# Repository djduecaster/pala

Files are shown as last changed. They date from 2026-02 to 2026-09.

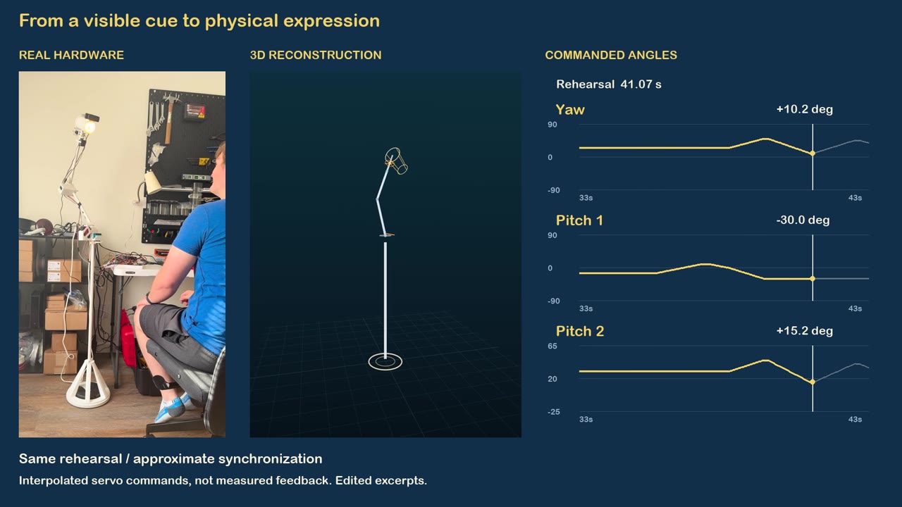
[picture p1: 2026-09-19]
docs/assets/pala-demo.jpg

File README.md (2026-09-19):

# PALA

**Programmable Autonomous Lamp Assistant** — a five-axis desk lamp with a little character.

PALA turns an IKEA NYMÅNE lamp into a physical desk companion. It notices someone sitting down, acknowledges a look toward its camera, celebrates a thumbs-up, follows a pointing direction, and settles back into a breathing rest pose. This is my first robotics portfolio project: custom printed mechanisms, embedded control, camera perception, and expressive motion brought together in a supervised V1 demo.

https://github.com/user-attachments/assets/bdd66a1e-fc92-461a-8403-59784bc540fe

**[Download the full-quality PALA V1 demo](https://github.com/djduecaster/pala/releases/tag/v0.1.0)** · 1 minute 47 seconds

The simulator and joint charts reconstruct commanded motion; they are not measured servo telemetry.

## The interaction

| You… | PALA… |
|---|---|
| Sit down and work | Makes a small noticing movement |
| Look toward the shade camera | Gives an expressive greeting |
| Give a thumbs-up | Leans forward, recoils, and adds coordinated yaw/pitch oscillations |
| Point left or right | Turns toward that general direction, then returns |
| Turn back to work | Disengages and settles into rest |
| Leave it resting | Breathes gently, with occasional yaw motion |

The performances were tuned on the real lamp through repeated operator ratings. Small movements often read poorly, so the final gestures use larger coordinated changes and distinct timing. The shade-mounted camera also shaped the resting posture: a useful view and a convincing pose had to work together.

## How it works

Gemini interprets a stationary camera snapshot and returns structured observations of presence, apparent attention, and visible gestures. Local Python logic decides whether an observation is fresh and appropriate for the current interaction stage, then selects a fixed performance. The model never supplies servo angles.

```mermaid
flowchart LR
    C[Shade camera] --> S[Stationary snapshot]
    S --> G[Gemini observation]
    G --> B[Local behavior gates]
    B --> P[Fixed performance]
    P --> T[Trajectory and limits]
    T --> H[PCA9685 / five servos]
```

The core runtime retains four independent loops: perception, behavior, control, and hardware. Their shared contracts are `PerceptionState → ActionPlan → HardwareCommand`. Latest-value exchange avoids queues of old camera frames; execution applies configured joint limits, and the hardware loop has a deadman timeout. The deadman is software-only, not an independent electrical emergency stop;
hardware operation requires supervision. See the [architecture guide](docs/architecture.md).

| Layer | Implementation |
|---|---|
| Mechanism | IKEA NYMÅNE lamp, custom 3D-printed servo mounts, five hobby-servo joints |
| Compute and actuation | NVIDIA Jetson, PCA9685 PWM driver |
| Vision | Logitech shade-mounted camera, GStreamer capture, Gemini image observations |
| Control | Python, deterministic choreography, calibrated joint-to-servo mapping |
| Development | Mac dummy backends, browser simulator, gesture workshop, optional telemetry |
| Capture | Optional FFmpeg POV recording and frame/command logs |

## Try it without hardware

Install Python 3.10–3.12 and [uv](https://docs.astral.sh/uv/), then:

```bash
git clone https://github.com/djduecaster/pala.git
cd pala
uv sync
PALA_MAX_RUNTIME_S=3 uv run python -m pala.main --mode dev
uv run pytest -q
```

The default runtime holds position using dummy backends. It does not start the live camera-driven performance or call Gemini.

For the local motion simulator:

```bash
uv run python tools/primitive_sim/run.py --scenario studio --port 8766
```

Open <http://127.0.0.1:8766/tools/primitive_sim/web/lamp_sim.html>. The [simulator guide](tools/primitive_sim/README.md) covers playback and joint checking. Simulation is a preview of commanded geometry, not a physical validation.

For the physical demo, follow the [Jetson workflow](docs/jetson_agent_workflow.md), then the [live interaction guide](docs/live_interaction.md). Hardware runs require the calibrated mechanism, a clear workspace, the established zero posture, and local credentials. The live tool moves to rest and automatically arms after its startup checks. Rest and shutdown zero are intentionally different positions.

## V1 boundaries

This is a working, supervised prototype rather than continuous human tracking. Model requests introduce variable latency; observations pause during motion, and the seated demo framing is deliberately constrained. Pointing selects left/right choreography rather than locating an exact object. Hobby servos provide no measured joint feedback, so commanded trajectories and simulator traces cannot establish actual position. The fifth joint is available but largely unused in the final gestures because of its mechanical limitations.

V1 is a completed portfolio milestone. A future version could improve the mechanism, sensing, and responsiveness, but those are separate work rather than requirements for this demo.

## Recreating and reusing PALA

Start with the [recreation guide](docs/recreating_pala.md) for parts, calibration,
system dependencies and staged bring-up. CAD/STL and a few hardware details are
still pending; this is a documented prototype rather than a complete build kit.
Software and textual documentation are [MIT licensed](LICENSE).
[Separate scope rules](docs/licensing.md) apply to media and CAD.

## Explore the project

- [Documentation index](docs/README.md): current guides and dated evidence
- [Live interaction](docs/live_interaction.md): behavior, controls, timing, and limitations
- [Gesture workshop](docs/gesture_workshop.md): pose and performance tuning
- [POV recording](docs/pov_recording.md): camera-only and live-demo capture
- [Robot configuration](config/robot.yaml) and [desk performances](config/desk_performances.json)
- [Portfolio media](docs/portfolio_media.md): release asset and local production archive

`pala/` contains the runtime; `tools/` contains operator tools and simulator sidecars; `tests/` covers contracts and software behavior. Videos, raw captures, model files, and archived working notes remain local and ignored by Git. Passing software tests does not establish physical acceptance of a new motion recipe.

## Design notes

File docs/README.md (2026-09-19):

# PALA documentation

PALA V1 is a supervised physical desk-companion demo. The default runtime holds
position; the opt-in live interaction uses camera snapshots and Gemini observations
to select locally controlled gestures. See the [project overview](../README.md).

| Guide | Purpose |
|---|---|
| [Recreating PALA](recreating_pala.md) | Parts, calibration, setup and remaining build details |
| [Licensing](licensing.md) | MIT software license and media/CAD scope |
| [Architecture](architecture.md) | Four loops, data contracts, model boundary, and safety limits |
| [Live interaction](live_interaction.md) | Current camera-driven V1 demo and rehearsal evidence |
| [Portfolio media](portfolio_media.md) | Demo release and ignored local production archive |
| [POV recording](pov_recording.md) | Optional live camera recording and stationary intro capture |
| [Manual interaction](manual_interaction.md) | Operator-triggered performances without Gemini |
| [Gesture workshop](gesture_workshop.md) | Tune and review individual physical performances |
| [Simulator](../tools/primitive_sim/README.md) | Local geometry, primitive tuning, and scripted playback |
| [Jetson workflow](jetson_agent_workflow.md) | SSH, tmux, deployment, and shared-shell conventions |
| [Telemetry](../tools/telemetry/README.md) | Optional camera/command viewer and historical replay |
| [Attention probe](attention_probe.md) | Stationary-view model diagnostic without model-triggered motion |
| [Single greeting test](live_greeting.md) | Earlier, explicitly armed one-greeting diagnostic |
| [Model transport](gemini_openai_sdk.md) | Generic endpoint diagnostics and credential conventions |
| [Memory boundary](memory_architecture.md) | Session bookkeeping and excluded persistent memory |
| [Workshop evidence](workshop_2026-09-07.md) | Dated operator ratings for specific gesture versions |
| [Known issues](bug_log.md) | Dated review backlog; entries are not newly reproduced findings |

Simulation and command traces do not measure physical joint position. Historical
ratings apply to the recorded recipe version, not automatically to later tuning.
Old competition, migration, and session-planning documents are outside the current
published guide set; source history preserves their context.

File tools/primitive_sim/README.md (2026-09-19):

# Lamp Sim (Sidecar Tool)

Lamp Sim is a sidecar workflow for quickly understanding primitives, joint geometry, and behavior loops before hardware runs.

It keeps runtime behavior math aligned by reusing `TrajectoryExecutor` from `pala/control/executor.py`.

## Unified shell (recommended)

Run the Lamp Sim sidecar server:

```bash
uv run python tools/primitive_sim/run.py --scenario studio --port 8766
```

Then open the unified shell:

```text
http://127.0.0.1:8766/tools/primitive_sim/web/lamp_sim.html
```

The shell provides navigation between Studio, Joint Checker, and Playback.
Generate a suite trace in Studio before opening Playback. All modes are local
simulation tools; they do not command hardware or establish physical acceptance.

## Primitive Studio mode (recommended)

Run the interactive tuning tool:

```bash
uv run python tools/primitive_sim/run.py --scenario studio --port 8766
```

Raw mode URL:

```text
http://127.0.0.1:8766/tools/primitive_sim/web/index.html?studio=1
```

Studio, Joint Checker, and Playback are available from this same server instance.

Studio features:
- Select any runtime primitive (`hold`, `home`, `move_to`, `gaze_to`, `glance`, `nod`, `breath`, `orient_to_zone`)
- Tune primitive command fields
- Live auto-run preview with configurable debounce (default 200ms)
- Run preview simulation with 3D lamp playback
- Compare mode: baseline (cyan) vs draft (orange) in `overlay` or `split`
- Save tuned values to baseline params
- Save all baseline params in one write (`Save All`)
- Reload from baselines on startup
- Camera toolbar (`zoom +/-`, `orbit <- ->`, `reset view`) + mouse-wheel zoom
- Parameter filter and expanded nudge controls (`--`, `-`, `+`, `++`)
- Top bar mode buttons: switch between Studio, Joint Checker, and Playback
- `Run Suite Trace` button: generates `logs/primitive_sim/latest_trace.json` and opens playback

## Joint checker mode

Run the dedicated joint slider page:

```bash
uv run python tools/primitive_sim/run.py --scenario joint_checker --port 8766
```

Raw mode URL:

```text
http://127.0.0.1:8766/tools/primitive_sim/web/joint_checker.html
```

Joint Checker, Studio, and Playback are available from this same server instance.

Joint checker features:
- Per-joint sliders generated from `joint_names` + `joint_limits_rad`
- Live angle readouts in radians and degrees
- 3D pose rendering driven by current slider values
- Camera toolbar (`zoom +/-`, `orbit <- ->`, `reset view`) + mouse-wheel zoom
- Per-joint `+/-` nudge buttons adjacent to angle input
- DH parameter table loaded from `config/robot.yaml`
- Top bar mode buttons and `Run Suite Trace` button

## Baseline params file

Default path:

```text
tools/primitive_sim/baseline_params.json
```

Override path:

```bash
uv run python tools/primitive_sim/run.py --scenario studio --baseline path/to/baseline.json
```

Baseline schema stores command defaults per primitive plus metadata:

```json
{
  "version": 2,
  "updated_by": "primitive_studio",
  "updated_at_utc": "2026-02-27T00:00:00Z",
  "primitives": {
    "breath": {"amp_rad": 0.08, "period_s": 6.5, "rate_rad_s": 1.0}
  }
}
```

Baseline loading is strict:
- Baseline files must already be v2.
- Missing primitive payloads or invalid command fields fail fast.

## Trace modes (existing CLI)

Generate suite trace:

```bash
uv run python tools/primitive_sim/run.py --scenario suite --serve
```

Generate one primitive trace:

```bash
uv run python tools/primitive_sim/run.py \
  --scenario single \
  --primitive nod \
  --duration-s 1.2 \
  --amp-rad 0.2 \
  --rate-rad-s 1.8 \
  --serve
```

Generate without serving:

```bash
uv run python tools/primitive_sim/run.py --scenario suite --output logs/primitive_sim/latest_trace.json
```

## Scripted scenarios

Use `--scenario script --script <file.json>`.

Script format:

```json
{
  "segments": [
    {
      "name": "home",
      "max_s": 2.0,
      "stop_on_done": true,
      "action": {
        "primitive": "home",
        "command": {"rate_rad_s": 1.2},
        "confidence": 1.0,
        "style": "calm"
      }
    }
  ]
}
```

## Viewer geometry sources

Viewer geometry is included in trace metadata and used by the 3D renderer.

Priority:
1. `dh_params`-derived values from `config/robot.yaml` (link lengths + theta offsets)
2. Explicit overrides from `lamp_geometry` sections
3. Viewer defaults for missing values

Pitch convention:
- Viewer defines all pitch joints about local `-Z`.
- Pitch1 and pitch3 use `theta = theta0 + q`.
- Pitch2 uses `theta = theta0 - q`: the operator confirmed positive pitch2
  opens/lifts the elbow away from the ground. This display convention applies
  to both Playback/Studio and Joint Checker; it does not reverse servo commands.

Supported override locations:
- `lamp_geometry`
- `sim_viewer.lamp_geometry`
- `primitive_sim.lamp_geometry`
- `tools.primitive_sim.lamp_geometry`

Example:

```yaml
sim_viewer:
  lamp_geometry:
    mast_height_m: 1.28
    hub_rise_m: 0.02
    upper_arm_len_m: 0.52
    fore_arm_len_m: 0.42
    wrist_stub_len_m: 0.08
    shade_neck_len_m: 0.08
    shade_len_m: 0.18
    shade_base_radius_m: 0.068
    shade_tip_radius_m: 0.046
    pitch1_zero_offset_rad: 1.57079632679
    pitch2_zero_offset_rad: 0.0
    pitch3_zero_offset_rad: 0.0
```

## Scripted desk interaction (simulation only)

Generate the current expression study, then serve this repository locally:

```bash
uv run python -m tools.primitive_sim.social_scene
uv run python -m http.server 8766 --bind 127.0.0.1
```

Open:

```text
http://127.0.0.1:8766/tools/primitive_sim/web/index.html?studio=0&trace=/logs/primitive_sim/desk_scene.json
```

Use **Play / pause** above the lamp or jump between labeled moments. The scene
order and captions come from `tools/primitive_sim/desk_scene.json`; motion comes
from the same `config/desk_performances.json` recipes as the live demo.
Regenerate the trace after recipe changes instead of relying on an old duration
or a hand-copied pose list.

Human actions are captions. This tool makes no Gemini requests, opens no camera,
and writes no hardware output. It runs the production executor at 80 Hz with
unity style scales and 1e-6-radian completion tolerance, and checks configured
target limits. It does not establish physical clearance, camera framing, measured
servo position, or recognition accuracy. For the real supervised behavior and its
rehearsal boundaries, see [live interaction](../../docs/live_interaction.md).

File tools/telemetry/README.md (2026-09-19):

# Telemetry sidecar

Telemetry runs separately from the four-loop runtime. Its default live view
(`runtime_core`) shows the camera preview, capture freshness/source health,
actions, and commanded joint angles. Joint values are commands, not measured
servo position or proof of hardware application/deadman health.

The supervised demo's semantic observations and execution reports live in its
own run logs; see [live interaction](../../docs/live_interaction.md). Old V3/V4
reasoning, case review, and dataset modules remain for historical replay. Current
runs do not emit the deleted planner's semantic streams.

## Live viewer

Start the intended runtime separately, following its operator guide. From the
repository root on the Mac, with your SSH alias configured:

```bash
uv run python -m tools.telemetry.mac_viewer \
  --mode live --focus runtime --jetson-host jetson-wifi
```

The GUI needs a Tk-compatible Python interpreter. If your environment requires
one, set `UV_PYTHON` to that interpreter's path. Do not launch another runtime
just to view an already-running demo.

Read-only diagnostic checks are available with:

```bash
uv run python -m tools.telemetry.doctor --help
```

Capture timestamps and viewer receive times are separate. Monotonic clocks from
different machines cannot be subtracted directly. A command sampled alongside a
preview frame does not demonstrate physical execution.

## Saved sessions and historical tools

Use a new local session directory for capture:

```bash
uv run python -m tools.telemetry.pipeline capture \
  --save-session logs/telemetry/session_001 --jetson-host jetson-wifi
uv run python -m tools.telemetry.pipeline compile logs/telemetry/session_001
uv run python -m tools.telemetry.mac_viewer \
  --mode replay --replay logs/telemetry/session_001 --focus runtime
```

The pipeline also offers `review`, `export`, and `report`. Inspect the relevant
subcommand's `--help` before using historical curation features. Indexed review
requires a compiled `session.db`; historical case/reasoning panels may be empty
for current sessions. Their labels are not current runtime model decisions.

Capture artifacts can include frames, event JSONL, indexes, a SQLite database,
and quality reports. Keep these local, including any camera images. Quality
reports describe captured data health, not physical safety or robot reliability.
Known issues from prior review are tracked in the [issue backlog](../../docs/bug_log.md).

Telemetry failure must not prevent core control/safety operation. Optional
[POV recording](../../docs/pov_recording.md) uses its own encoder and timing logs.

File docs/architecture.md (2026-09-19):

# PALA Architecture

## Runtime Loops

- Perception loop: approximately 15-30 Hz
- Behavior loop: approximately 2-5 Hz
- Control loop: approximately 50-100 Hz
- Hardware loop: approximately 50-200 Hz with deadman timeout

The stable runtime contract remains:

```text
PerceptionState -> ActionPlan -> HardwareCommand
```

## Runtime modes

The default behavior emits one persistent `hold` action and uses dummy backends
in dev mode. Opt-in manual performances and the supervised camera/Gemini demo
share the same four loops and typed control/hardware contracts.

The [live interaction](live_interaction.md) runner uses stationary camera snapshots
for semantic observations. Local code selects and sequences fixed performances;
the model never writes joint targets or hardware commands.

## Perception

The active perception path performs capture only:

```text
FrameSource -> PerceptionNode -> LatestFrameCache + PerceptionState
```

`PerceptionState` reports frame identity, freshness, timing, FPS, and source
health. It does not report people, objects, zones, gestures, or pointing.

Local DeepStream detection is not part of the active runtime. Semantic image
interpretation runs only in the opt-in model tools.

## Behavior

The behavior package includes a hold-only default policy, manual performance
request gate, model transport clients, and validation for social observations.
The live-demo supervisor uses one model request in flight and rejects stale,
invalid, or context-mismatched results before requesting a local performance.

## Control and Hardware

Control remains deterministic. `TrajectoryExecutor` converts typed
`ActionPlan` objects into rate-limited, joint-clamped `HardwareCommand` objects.
The hardware loop applies commands through dummy or PCA9685 servo backends and
enforces the deadman timeout independently of behavior/model availability.

The configured rates are 20 Hz perception, 3 Hz behavior, 80 Hz control, and
120 Hz hardware. The deadman is a software check in the hardware thread; it
is not an independent electrical watchdog.

The executor uses latest-intent arbitration: a different intent replaces the
active primitive, equivalent intents preserve it, and a completed action ID
does not restart. `cancel_current` remains in the stable contract but is not
interpreted by the executor. Gesture sequencing must account for this behavior.

The executor starts at a software zero estimate and exposes commanded
completion, not measured physical arrival. The current servo interface has no
position feedback. Following operator confirmation with the calibration tool,
pitch2's software limits are -25 to +65 joint degrees. These match its
unsaturated servo mapping; scale 2 and offset 50 remain unchanged. Physical
behavior was confirmed by the operator, not measured by software feedback.

Simulation supplies a private clock to the same executor. It does not patch
global time or change the runtime's real monotonic clock. Configuration rejects
nonfinite or invalid rates/limits/styles, and the servo backend validates the
entire command before beginning channel writes. I2C failures during a valid
batch are still possible; software validation is not bus-level atomicity.

Standalone gesture dry-runs use dummy hardware regardless of runtime mode.
The main runtime's four-loop deadman does not apply to these standalone tools.

## Logging

The default runtime writes:

- `perception.jsonl`: capture state and source health
- `actions.jsonl`: emitted hold actions
- optional preview image and metadata files for telemetry

Manual/live runs also write `interaction.jsonl` and recipe/configuration snapshots.
Live model observations, source images, and session settings are recorded under
`logs/attention_probe/<session>/`; see the live interaction guide.

Live telemetry defaults to the runtime view. Joint positions and enable state
are explicitly commanded values; applied hardware and deadman status are
unavailable without a structured status producer. Historical reasoning,
capture/replay, and curation remain optional sidecar tooling.

## Opt-in manual performances

`--manual` enables the [manual interaction](manual_interaction.md). The supervisor
polls terminal commands without adding a worker loop. The behavior loop gates
requests and publishes immutable performance recipes through a latest-value
channel. The control loop expands each recipe into the existing typed
`ActionPlan` steps and executes them through `TrajectoryExecutor`;
`PerceptionState`, `ActionPlan`, and `HardwareCommand` schemas are unchanged.
Control feedback reports commanded completion to the behavior gate.

This control-rate sequencer preserves short holds, rejects normal preemption,
and permits an explicit shutdown trajectory from the current command estimate.
It uses unit style multipliers and 1e-6-radian commanded completion tolerance,
matching the workshop. Default executor tolerance remains unchanged. Rest and
zero are distinct. Ctrl-C stops without recovery. Once manual commands have
started, a hardware deadman expiry stops the session without automatic resume.

Manual runs add recipe/configuration snapshots and `interaction.jsonl` execution
reports; their `actions.jsonl` records step transitions instead of hold-only
decisions. The separate live-demo composition has supervised rehearsal evidence described
in the live interaction guide. This does not establish unattended reliability.

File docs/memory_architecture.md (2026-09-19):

# Behavior memory boundary

The default hold policy has no scene interpretation or model memory. The opt-in
live interaction maintains session-local state: current stage, active performance,
presence already noticed, greeting/excitement limits, pointing release/cooldown,
observation generation, and automatic rearming.

Presence persists across automatic rearms so a seated person does not repeatedly
trigger notice. Two valid absent observations at rest spanning four seconds allow
a later arrival to be noticed again. This is bookkeeping, not person recognition.
The state is not persistent identity or autobiographical memory. A separate
summarizer, long-term learning, and transcript memory are outside V1.

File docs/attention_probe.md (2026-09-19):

# Gemini attention probe

This experiment starts the existing four-loop manual runtime, enters rest, and
holds there while you collect four labeled observations. Gemini interprets apparent
attention toward the lamp; its answers never request movement. Startup and normal
shutdown are the only motion permitted in probe mode. The camera is on the shade,
Capture uses 1280×720 MJPEG at a requested 30 FPS. Stationary comparisons showed
wider horizontal coverage than 640×480 and essentially the same coverage as
1920×1080. The preview is downscaled without cropping.

This first experiment uses only the stable rest viewpoint. Current rest is
`[yaw=0, pitch1=-40, pitch2=+25, roll=0, pitch3=0]` in joint degrees.

## Offline Mac check

From the repository root:

```bash
uv run python -m tools.attention_probe --mode dev --probe-mock
```

Dummy camera, dummy servos, and explicitly labeled mock responses; no API call or
key needed. The mock always returns uncertain/wait and does not analyze the image.
Wait for `PROBE READY`, then type a number and press Enter.

| Number | Your position at the end of the countdown |
|---|---|
| 1 | Outside the frame: empty scene. |
| 2 | Walk into view without looking at the camera. |
| 3 | Look directly toward the camera. |
| 4 | Look toward the wall beside the camera. |

Each number starts a **five-second countdown**. Capture uses the first available
fresh frame taken after the deadline; scheduling/camera delay is logged. A frame
must be at most 500 ms old. If none arrives within two additional seconds, the
trial ends without an API call. Stay in position until `SNAPSHOT saved` appears.
Then you can return to the keyboard while Gemini responds.

Repeat numbers freely, one trial at a time. New trial requests while counting down
or awaiting a response are rejected rather than queued. Each request contains only
the image and a fixed resting-state prompt; the scenario number and description
are saved locally and deliberately excluded from the model input.

## Key and model setup on Jetson

Use a Gemini API key, not a browser login. Either export `GEMINI_API_KEY` in the
shell launching the runner, or save the key alone in a file outside the repository,
for example `~/.config/pala/gemini_api_key`, and use `--gemini-key-file` below.
`PALA_GEMINI_API_KEY` and `GOOGLE_API_KEY` are also recognized. No key is accepted
on the command line as a literal value or written to probe logs.

To create the key file without putting the key in shell history (Jetson Bash):

```bash
install -d -m 700 ~/.config/pala
(umask 077; read -r -s -p 'Gemini API key: ' key; echo;
 printf '%s' "$key" > ~/.config/pala/gemini_api_key)
chmod 600 ~/.config/pala/gemini_api_key
```

For a temporary environment variable instead (Jetson Bash):

```bash
read -r -s -p 'Gemini API key: ' GEMINI_API_KEY; echo
export GEMINI_API_KEY
export PALA_GEMINI_MODEL='YOUR_AVAILABLE_GEMINI_MODEL_ID'
```

If you maintain exports in `~/.config/pala/env.sh`, source it yourself in that
terminal first. The probe does not read or execute shell configuration files.
There is deliberately no hardcoded model version: use an image-capable Gemini
model available to your account. `--gemini-model` overrides `PALA_GEMINI_MODEL`.
Missing credentials/model fail before hardware initialization. The key's validity
and model access are checked only when the first trial makes a real request.

## Physical session

Stop the existing manual/workshop runtime first; do not start competing servo or
camera owners. After returning to and establishing zero, run in the shared `pala`
tmux session from `~/pala`:

```bash
uv run python -m tools.attention_probe --mode jetson_full --enable
```

Or with a key file:

```bash
uv run python -m tools.attention_probe --mode jetson_full --enable \
  --gemini-key-file ~/.config/pala/gemini_api_key \
  --gemini-model YOUR_AVAILABLE_GEMINI_MODEL_ID
```

Confirm `ZERO` when prompted. Startup moves to rest automatically. The ground-facing
zero view is not submitted. Wait for `PROBE READY` and use 1–4. Only the triggered
snapshots are sent to Google's Gemini API; there is no continuous upload. These
images and the responses are also saved locally.

- `help` / `?`: show the four scenarios and common commands.
- `status`: show runtime posture and progress.
- `cancel`: cancel a countdown; an already-sent API request cannot be recalled.
- `shutdown` / `q` / `quit`: return to zero, hold two seconds, disable, and exit.
- `stop` / `abort` / Ctrl-C: disable and exit without recovery motion.
- Closing input or first SIGTERM requests normal shutdown, as in the manual runner.

Gesture commands (`greet`, `demo`, etc.) are blocked in probe mode. The auxiliary
network worker cannot access the gesture gate or actuators. It uses a 20-second
request timeout and disables SDK retries; control and hardware loops continue
while waiting. Shutdown does not wait for that worker. An unfinished request is
logged as abandoned on exit; the remote service may still finish processing it.

## Results

Each trial prints person presence, apparent attention, `acknowledge` or `wait`, a
short visible-evidence sentence, and elapsed request/validation latency. These
are proposals only. An invalid or failed response is labeled explicitly, not
silently converted into a valid wait decision. A single snapshot cannot establish
walking direction or reliably measure precise eye gaze; sideways-looking case 4
is intentionally a useful ambiguity test.

Outputs live in a unique `logs/attention_probe/<timestamp>_<id>/` directory:

- `session.json`: model, timing, scenarios, mock flag, and posture context.
- `prompt.txt`: exact fixed prompt.
- `performances.json`: recipe snapshot, including exact rest angles for this run.
- `<trial-id>.jpg`: exact JPEG submitted (up to 960 pixels on its longest side).
- `trials.jsonl`: scenario labels, capture age/delay, provider response content and
  usage when available, validated decision, failures, and measured latency.

Normal runtime logs still live under `logs/runs/`. Logs/images are ignored by git.
Use `--probe-output PATH` to select another parent directory. Keep images private
unless you deliberately select them for a portfolio artifact.

The implementation reuses PALA's retained model transport and Google's documented
[OpenAI-compatible image input and JSON output interface](https://ai.google.dev/gemini-api/docs/openai).
It does not restore the removed behavior system. This first experiment tests
acknowledge-versus-wait from rest; sustained attention and disengagement are later
contracts, after we inspect the camera's attention posture.

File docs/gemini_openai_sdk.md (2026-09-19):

# Model transport diagnostics

The default runtime remains hold-only. Generic transport probes run independently
and do not actuate the lamp. The implemented camera/Gemini demo is documented in
[live interaction](live_interaction.md); its validated semantic observations
feed local gesture selection.

The surviving transport is under `pala/behavior/model_clients/`. It supports
provider-aware URL normalization and chat requests. `tools/model_provider_probe.py`
checks basic text and JSON responses; it no longer uses deleted V4 prompts,
skills, or decision schemas.

```bash
uv run python tools/model_provider_probe.py --help
```

For an explicitly configured model endpoint, use `--provider`, `--base-url`,
and `--model`, or the existing `PALA_MODEL_PROVIDER`, `PALA_COSMOS_BASE_URL`,
and `PALA_COSMOS_MODEL` variables. The probe reads credentials from
`PALA_COSMOS_API_KEY`; keep them in the local/Jetson secret environment, never
in shell examples committed to Git. Running the probe sends requests to the
configured service. A transport result does not establish behavior quality.

Image capture and image/video diagnostics remain in
`tools/capture_cosmos_api_inputs.py`, `tools/cosmos_image_probe.py`, and
`tools/cosmos_video_probe.py`. Their historical names remain for now. Inspect
each tool's help before use; camera source and endpoint must be explicit.

The `cosmos` configuration block is retained for these diagnostic tools.
`pala.main` does not consume its enabled flag to construct a planner. The old
runtime planner smoke script was removed because its assertions referenced
behavior that no longer exists.

Before changing a provider or model, check the selected provider's current model
and parameter documentation. Historical model IDs and quota assumptions are
not a current recommendation. See [Google's compatibility reference](https://ai.google.dev/gemini-api/docs/openai).

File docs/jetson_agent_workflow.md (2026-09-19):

# Jetson agent workflow

This document describes the direct Mac-to-Jetson workflow for agents and
operators. It is intentionally separate from the PALA runtime architecture:
the Jetson shell and tmux session are operator tooling, not another runtime
loop.

## First-time setup

Complete the [recreation guide](recreating_pala.md#software-environment) before
using the deployment scripts on a fresh Jetson. Their plain-venv bootstrap is not
a system dependency installer and does not expose system PyGObject/GStreamer.

## SSH paths

The development setup uses two locally configured SSH aliases (configure these
for your own Jetson before using the examples):

- `jetson`: the USB device-mode path at the `192.168.55.x` link-local address.
- `jetson-wifi`: the Jetson's normal Wi-Fi address.

Use `jetson-wifi` for direct agent work when Wi-Fi is available. The existing
deployment scripts currently call the `jetson` alias directly, so changing
`JETSON_HOST` on the `make` command line does not yet change where
`deploy_jetson.sh` or `run_jetson.sh` connect.

Check the resolved target before troubleshooting a connection:

```bash
ssh -G jetson-wifi | grep -E '^(hostname|user|port) '
```

## Shared tmux session

The `pala` tmux session lives on the Jetson. It stays alive independently of
the SSH connection, which lets an operator attach to the same shell that an
agent is using.

Create it if needed:

```bash
ssh -T jetson-wifi 'tmux new-session -A -d -s pala'
```

Attach from a visible Mac terminal:

```bash
ssh -t jetson-wifi 'tmux attach -t pala'
```

Detach with `Ctrl+B`, then `D`. Detaching leaves commands running. Typing
`exit` ends the shell in that tmux pane.

## Agent interaction

Agents should use one command at a time and capture the pane after the command
has had time to finish. The shared pane is an interactive surface, so an agent
should not send keys while the operator is typing or while an interactive
program owns the prompt.

Send a short, literal command visibly into the shared shell:

```bash
ssh -T jetson-wifi \
  'tmux send-keys -t pala -l "hostname; pwd"; tmux send-keys -t pala Enter'
```

Read the visible command and recent output:

```bash
ssh -T jetson-wifi 'tmux capture-pane -p -t pala -S -80'
```

Check the pane without changing it:

```bash
ssh -T jetson-wifi \
  'tmux display-message -p -t pala "#{pane_current_command} #{pane_current_path}"'
```

For commands that need reliable exit status, structured output, or complex
quoting, agents should use a normal noninteractive SSH command and report the
result in the conversation. `send-keys` is for shared visibility; it is not a
replacement for a script runner.

## Long-running PALA runs

Keep the shared `pala` shell available for inspection and run long-lived PALA
processes in a named tmux window:

```bash
ssh -T jetson-wifi \
  'tmux new-window -d -t pala: -n pala-run "cd ~/pala && ./run_on_jetson.sh"'
```

List windows and capture the run window:

```bash
ssh -T jetson-wifi 'tmux list-windows -t pala'
ssh -T jetson-wifi 'tmux capture-pane -p -t pala:pala-run -S -120'
```

Before starting another run, check whether `pala-run` already exists and
whether a runtime is still active. Do not stack multiple hardware runtimes on
the same Jetson.

## `make go` and a future tmux target

Today, `make go` does this:

1. `deploy_jetson.sh` synchronizes the Mac checkout to `~/pala`.
2. `run_jetson.sh` opens a foreground SSH command and runs
   `run_on_jetson.sh` directly.

That foreground behavior is useful for a normal agent command, but it does not
create or attach to tmux. Automatically attaching would also keep `make go`
running for the entire lifetime of PALA, which makes the command awkward for
noninteractive agents.

The preferred future change is an explicit opt-in target such as
`make go-tmux`:

- deploy to the selected SSH alias;
- start `run_on_jetson.sh` in a dedicated `pala` tmux window;
- return the command promptly;
- let the operator stay attached to the session and let the agent use
  `capture-pane` for text logs.

An optional `make go-attach` could provide the foreground attached behavior for
manual demonstrations. Keeping these behaviors separate avoids changing the
meaning of the existing `make go` command. Implementing either target requires
an explicit change to the deployment scripts and Makefile; this document does
not change those scripts.

## Safety and logging notes

- Keep Mac and Jetson paths explicit in every command.
- Use `PALA_LOG_LEVEL=INFO` or `DEBUG` only when the extra output is useful.
- Prefer the run-scoped files under `~/pala/logs/runs/` for post-run evidence;
  use `make pull-logs` after a run when its SSH target is correct.
- tmux persistence does not replace the runtime deadman timeout or any local
  hardware safety limit.

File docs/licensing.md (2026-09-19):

# License and scope

PALA's original software source and associated textual documentation are licensed
under the [MIT License](../LICENSE), copyright 2026 Dylan Duecaster. This includes
Python tools, browser simulator code and project configuration. Preserve the
copyright and license notice when redistributing covered material.

The MIT grant does **not** cover portfolio videos, photographs (including the
README thumbnail), audio/music, or CAD/mechanical design files. These materials
are provided for viewing/reference only unless accompanied by separate terms;
no additional reuse license is granted here. Third-party materials and dependencies
retain their own licenses. The existing camera-mount STEP fit-check artifact is
not a complete released CAD package.

CAD licensing will be stated when the full design package is released. A
hardware-specific license such as CERN OHL v2 can be considered at that point;
see [OSHWA's hardware licensing guide](https://certification.oshwa.org/process/hardware.html).

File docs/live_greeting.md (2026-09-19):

# Supervised live Gemini greeting

This earlier diagnostic lets you judge response timing by watching the lamp move.
For the current V1 demo, use [live interaction](live_interaction.md). The operator
chose to skip additional numbered-camera and shadow-only trials. It is explicitly
armed and allows one Gemini-triggered greeting per arm, not autonomous ongoing
interaction. Rest is `[0, -40, 25, 0, 0]` joint degrees, accepted for a seated,
close-range demo; capture is 1280×720 MJPEG.

Stop the framing workshop and camera-only runtime before launching. This runner
owns both camera and servo output, and continues publishing the existing preview
tap for the Mac browser. From `~/pala` on Jetson:

```bash
uv run python -m tools.live_greeting \
  --mode jetson_full --enable \
  --gemini-key-file ~/.config/pala/gemini_api_key \
  --gemini-model "${PALA_GEMINI_MODEL:?Set an available image-capable Gemini model first}"
```

Confirm established physical zero. Startup moves to rest. Wait for
`LIVE TEST READY at rest, disarmed`, then type `arm` and Enter. You have five
seconds to get situated. During the next 60 seconds, one current rest-view image
at a time is sent to Gemini, with a one-second pause after each reply. The first
valid, eligible `acknowledge` requests the accepted greeting through the existing
manual behavior gate. The lamp finishes at attention; observations stop. No
automatic settling or rearming occurs.

The gate requires idle rest, a healthy fresh camera frame, matching posture/request
generation, and an image no more than six seconds old when deciding to move. A
pause, shutdown, or posture change invalidates pending decisions. Invalid responses,
unknown attention, waits, and network failures do not trigger motion. API requests
retain the probe's 20-second timeout and zero SDK retries. Failed trials can be
rearmed once the pending call finishes. Image age includes inference time; freshness
checks cannot prove someone has not turned away while Gemini was answering. This
experiment measures that limitation rather than hiding it with another detector.

Commands:

- `arm`: begin the five-second positioning delay and one-greeting observation window.
- `pause` / `cancel`: disarm and discard pending decisions; an active gesture finishes.
- `reset`: disarm and request settling back to rest; waits for completion before rearm.
- `status`: show posture, armed state, and pending request status.
- `help`: show these commands.
- `shutdown` / `q`: disarm through shutdown state, return to zero, then disable and exit.
- `stop` / Ctrl-C: disable and exit without recovery motion.

After the first greeting, evaluate both reaction timing and the camera's attention
view. If suitable, use `reset` then `arm` for another trial. The new rest-to-greeting
and settling transitions still require operator acceptance.

Logs use `logs/attention_probe/<session>/`, with `session.json` identifying
`mode=live_greeting` and `motion_from_model=true`. Snapshots, prompt, recipes,
responses, decision eligibility, image age, and motion-request acceptance are
recorded. Runtime control logs remain under `logs/runs/`. These are commanded
positions, not physical feedback.

For an offline wiring check, use `--mode dev --probe-mock` and omit hardware/key
flags. Mock responses deliberately remain uncertain/wait, so they never greet;
automated integration tests inject an acknowledgment to verify dispatch with dummy
hardware. No live physical acceptance is implied by those tests.

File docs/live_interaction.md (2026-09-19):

# Supervised desk interaction

This opt-in V1 demo uses shade-camera snapshots and Gemini observations to select
fixed local performances: notice, greet, excitement, directional pointing, and
settling. It has been exercised in supervised Jetson rehearsals. The default
`pala.main` runtime remains hold-only. This guide describes the checked-in
configuration; individual rehearsal results below refer to their recorded version.

## Launch

Stop other camera/servo owners, establish physical zero, and run in a named tmux
window using the [Jetson workflow](jetson_agent_workflow.md):

```bash
cd ~/pala
export PALA_GEMINI_MODEL='YOUR_AVAILABLE_GEMINI_MODEL_ID'
uv run python -m tools.live_interaction \
  --mode jetson_full --enable \
  --gemini-key-file ~/.config/pala/gemini_api_key \
  --gemini-model "$PALA_GEMINI_MODEL"
```

Choose an image-capable model available to your account; the placeholder above
is not a real model ID. Complete [key and model setup](attention_probe.md#key-and-model-setup-on-jetson)
first. Credentials stay in the local secret file. Confirm `ZERO` only with
the lamp at the known starting posture. Startup moves to rest, then automatically
arms with a five-second countdown. Add `--record-pov` for optional
[POV recording](pov_recording.md).

For a Mac smoke test with dummy camera/servos and no API call:

```bash
uv run python -m tools.live_interaction --mode dev --probe-mock
```

Mock observations are uncertain and do not trigger social gestures. Automated
tests separately inject scripted observations to exercise dispatch.

## Interaction and controls

1. Enter the tested close-range seated camera view and work. Presence triggers
   quiet noticing once. Look toward the shade camera to invite greeting.
2. A clear thumbs-up with attention at rest or after noticing accepts greeting
   followed by excitement. No second cue is required between those movements.
   A thumbs-up after greeting can also trigger excitement, once per interaction.
3. After greeting or excitement, point clearly left or right in the unmirrored
   camera image. Hold the cue long enough for a snapshot. Release your hand
   between cues; another point requires a valid present-person/gesture-none
   observation and at least eight seconds since the last accepted point.
4. Return to work. Two valid away/absent observations spanning at least four
   seconds trigger settling. Before greeting, the away grace is 20 seconds.
5. Normal settling automatically rearms after a 0.75-second stationary pause.
   Presence memory prevents repeated notice/settle cycles for someone still
   working. Two valid absent-at-rest observations spanning four seconds permit
   a future arrival to trigger notice again.

Each arm has a 180-second observation window. Expiry disarms social decisions;
the current posture remains and enabled idle breathing may continue at rest.

| Command | Effect |
|---|---|
| `arm` | Start a five-second countdown; during breathing, wait for rest midpoint first |
| `pause` / `cancel` | Disarm observation, suppress automatic rearming, and suspend breathing |
| `reset` | Disarm and suspend breathing; settle if idle away from rest; during motion, issue again after completion |
| `breathe-on` / `breathe-off` | Enable/suspend subsequent idle cycles; active cycle finishes at midpoint |
| `status` | Report runtime and observation state |
| `shutdown` / `q` | Controlled return to zero, disable outputs, and exit |
| `stop` / Ctrl-C | Disable immediately without recovery motion |

After pause/reset, use `arm` to resume observations and `breathe-on` if desired.

## Current motion and observation settings

`config/desk_performances.json` is the live motion source of truth. Joint order
is yaw, pitch1, pitch2, roll, pitch3, in degrees:

| Pose | Values |
|---|---|
| Rest | `[0, -40, 25, 0, 0]` |
| Attention | `[25, -15, 30, 10, 0]` |
| Excited endpoint | `[35, -15, 25, 10, 0]` |
| Point left / right | `[70, -5, 15, 0, 0]` / `[-10, -5, 15, 0, 0]` |

Pointing holds three seconds then returns to attention. It follows a general
direction, not a triangulated target. Excitement leans pitch1 to +10, recoils
through -1 to -30 with staged yaw/pitch2 sweeps, then returns to its endpoint.

Idle breathing cycles pitch1 ±8 degrees around rest with pitch2 compensation;
every third cycle adds yaw ±6 degrees. Pitch3 remains zero. Current 16°/s rates
produce approximately two seconds of motion, followed by stationary waiting and
inference. This faster motion setting is distinct from the four-second breathing
cycles recorded in the September 12 rehearsal snapshots.

Requests use `reasoning_effort=minimal`, a 0.25-second inter-request pause, one
request in flight, and a 0.75-second stationary-frame wait. The lamp holds through
the model response. Capture cadence therefore includes motion and inference;
it is not continuous tracking or a fixed frame interval.

Gemini reports presence, apparent attention, visible gesture, and brief evidence.
Local code owns stage transitions, fixed recipes, limits, and execution. A
six-second image-age gate, current-camera freshness, and plan/stage/generation
matching reject invalid or obsolete observations. The worker cannot actuate.
Requests have a 20-second provider timeout and no automatic transport retries.
A later fresh observation may be requested after failure.

Early thumbs-up accepts a two-movement response with a 30-second continuation
expiry. Greeting must complete at its expected endpoint before excitement.
Pause, reset, disarm, rejection, failure, shutdown, or unexpected completion
clears the continuation. Lowering a hand during greeting does not cancel the
already accepted response; no image is interpreted between those movements.

## Rehearsal evidence and limitations

The September 12 full-choreography review recorded probe
`20260912_153135_3334c8` and runtime `20260912_153200`: notice, greeting, staged
excitement, both pointing directions, settling, breathing, sway, and a clean
controlled shutdown. The operator called it “a very successful run.” Across 32
valid responses, median request latency was 2.67 seconds; one stale result was
rejected. These are local rehearsal records, not a published benchmark.

The later minimal-thinking snapshot (`20260912_154543_5a0b12`, runtime
`20260912_154604`) recorded 17 valid responses with median 1.76 seconds
(range 1.37–4.51), no stale rejections, and completion of greeting, excitement,
left pointing, and settling. Operator feedback was “pretty much perfect.” That
snapshot was taken during an active run and does not establish final shutdown or
right pointing for that run. Latency comparisons were not same-image experiments.

Physical success is based on operator observation. Logs show commanded angles
and completion, not measured servo position, physical motion onset, or reliability
across users, lighting, and camera views. Earlier gesture ratings in the
[workshop report](workshop_2026-09-07.md) apply to those recipe versions.

Model observations and JPEGs are local under `logs/attention_probe/<session>/`;
command traces and configuration snapshots are under `logs/runs/<run>/`. Logs,
keys, and raw media are not required published assets. Simulator playback
validates configured motion, not physical clearance or Gemini recognition:

```bash
uv run python -m tools.primitive_sim.social_scene
```

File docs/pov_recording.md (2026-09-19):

# Lamp POV recording

## Stationary intro and stop-motion stills

After the live demo has returned to zero and shut down, record the downward
camera view without starting the robot runtime:

```bash
cd ~/pala
uv run python -m tools.record_intro --mode jetson_full
```

This opens only the configured camera. It does not initialize servos, command
zero, actively hold a pose, breathe, arm interaction, or contact Gemini. Leave
the lamp physically at the established zero posture. Stop other camera-owning
tools first; the live demo and intro recorder must not run together.

Recording starts as soon as camera frames arrive. The maximum duration is ten
minutes by default (`--seconds 1200` allows twenty minutes, up to one hour).
Use `--until-stopped` instead for no automatic duration limit; explicitly stop
the recording to finalize the video. Camera or encoder failures can still stop it.
Type `stop`, `q`, or `shutdown` then Enter, or press Ctrl-C, to finalize the MP4.
Here `shutdown` stops the camera recorder only; it never moves the lamp.

- `snap`: save a numbered, full-resolution JPEG after placing each group of parts.
- `status`: show recorded duration and still count.
- `help`: list commands.

Each launch creates a unique `logs/intro/<timestamp>_<id>/` folder containing
`pov.mp4`, the existing recorder timing/result files, and any `still_0001.jpg`
images. Use stills in the edit to build stop-motion without hands in frame.
The video is silent, at most 720p, 20 fps. Capture a light-switch sound separately
if desired. A failed or disconnected camera stops the tool after five seconds
without frames; the command reports failure while finalizing captured footage.

Mac smoke test (dummy images, no camera or servos):

```bash
uv run python -m tools.record_intro --seconds 2 --no-console
```

## Live interaction recording

Add `--record-pov` to the existing live demo command:

```bash
cd ~/pala
uv run python -m tools.live_interaction \
  --mode jetson_full --enable --record-pov \
  --gemini-key-file ~/.config/pala/gemini_api_key \
  --gemini-model "${PALA_GEMINI_MODEL:?Set an available image-capable Gemini model first}"
```

Normal zero confirmation applies. The live demo automatically arms after startup.
Recording starts when camera frames arrive, before automatic arming, and continues during gestures, breathing,
and snapshot pauses. Use `shutdown` to return to zero, disable outputs, and
finalize the video. It records at most ten minutes per launch. There is no audio.

The optional encoder requires `ffmpeg` with `libx264` on Jetson. A missing encoder
or recording failure logs a warning and does not stop lamp control. Check for
`POV recording started` and review `result.json` after a run; runtime success
alone does not mean video was saved successfully.

Outputs are printed at launch and stored under:

```text
logs/runs/<run>/pov_<id>/
  pov.mp4        H.264, at most 1280×720, 20 fps, no overlays
  session.json   dimensions, rate and monotonic start time
  frames.jsonl   source timing, repeated/stale frames, video timestamps
  encoder.log    encoder diagnostics
  result.json    written frame count and any recording error
```

The recorder shares the existing RGB frame cache; it never opens a second camera.
A separate worker resizes/encodes with bounded memory and two encoder threads.
The 20 fps file repeats frames when the source is slower. Its timing log marks
these and stale frames. The intro and live-demo entry points use fragmented MP4, writing playback
metadata early and fragments throughout the take. They disable the former
one-second encoding-lag abort; inspect frame timing afterward for any lag.
Direct PovRecorder callers retain the bounded-lag default. An interrupted
fragmented recording can still lose the unfinished tail. Quality, CPU headroom, and effective frame rate still need a
Jetson trial. This does not fix focus, glare, framing, or motion blur. Normal
shutdown finalizes MP4; power loss or forced process termination may leave it
unplayable.

Copy a chosen completed run to the Mac (substitute the printed run and POV IDs):

```bash
mkdir -p logs/pov_jetson
rsync -az jetson-wifi:~/pala/logs/runs/<run>/pov_<id>/ logs/pov_jetson/<run>/
```

Logs and videos stay Git-ignored. Trim the POV footage alongside your external
camera recording, then publish the reviewed edit as a GitHub Release asset and link it from the
README. Publishing is a separate step from local recording. Review the
frame log if you need to align motion and model events by monotonic timestamp.

For an entirely hardware-free smoke test on Mac:

```bash
PALA_MAX_RUNTIME_S=3 uv run python -m pala.main --record-pov
```

This records the dummy image source and verifies encoding, not the physical camera.

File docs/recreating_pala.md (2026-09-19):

# Recreating PALA V1

The software and demo recipes are available; the mechanical build package is not
complete yet. CAD/STL files will be added separately. The existing `tools/camera mount fit check 2.step`
is a camera-mount fit artifact, not the full mechanism design. You can run the simulator
now, but the repository is not yet a complete shopping-and-assembly kit.

## Parts and connections

| Component | Known build detail | Still needed for an exact replica |
|---|---|---|
| Lamp | IKEA NYMÅNE mechanism | Exact product variant |
| Compute | NVIDIA Jetson | Board variant and tested JetPack/OS version |
| Actuation | Five hobby servos, PCA9685 driver | Servo model per joint, driver board variant |
| Camera | Logitech USB camera mounted on shade | Model and mounting photo |
| Mechanical parts | Custom printed mounts | CAD/STL, material, print settings, bearings and fasteners |
| Power | Jetson and servo power connections | Supply ratings and annotated wiring photo |

The current configuration maps PCA9685 channels **0–4** to **yaw, pitch1, pitch2,
roll, pitch3**, respectively. It uses I²C **bus 7**, address **0x40**, and **50 Hz**
PWM. These are values for the existing build, not universal Jetson pin assignments.
Confirm the bus and board pinout for your hardware before connecting anything.

The missing wiring photo should label SDA/SCL, logic supply, servo V+, ground
connections, and supply ratings. Do not infer servo supply voltage from the
Jetson GPIO voltage or treat the Jetson header as a servo power supply. Keep the
lamp's lighting power separate from the low-voltage servo wiring; this repository
does not provide instructions for modifying mains wiring.

## Software environment

Start with the [README's Mac/dummy quickstart](../README.md#try-it-without-hardware).
Python dependencies are declared in `pyproject.toml` and locked in `uv.lock`.
The Jetson additionally needs system GStreamer/PyGObject, the JPEG/V4L2 capture
plugins, I²C device access, and optionally FFmpeg for recording. Those system
components are not installed by `uv sync`.

Use a JetPack-supported system Python within the project's Python 3.10–3.12
range. For a **fresh** Jetson checkout, create the environment with system package
visibility before syncing:

```bash
uv venv --python /usr/bin/python3 --system-site-packages
uv sync
uv run python -c "import gi; gi.require_version('Gst', '1.0'); from gi.repository import Gst; Gst.init(None); print(Gst.version_string())"
```

This is a setup recipe, not a claim that a clean Jetson installation was retested.
The exact tested OS/package inventory is still to be recorded. If `gi` cannot be
imported, check both the system installation and the virtual environment's Python
version; installing Python requirements alone will not resolve a missing system
GStreamer installation. Do not replace an existing working environment blindly.

Complete this environment setup **before** `make go` or `run_on_jetson.sh`.
Their automatic bootstrap creates a plain virtual environment and does not expose
system GStreamer packages. They are not a fresh-Jetson installer.

The deployment scripts assume a locally configured `jetson` SSH alias; see the
[Jetson workflow](jetson_agent_workflow.md). `make go` starts the default runtime,
not the camera-driven social demo.

## Zero, directions, and calibration

**Joint degrees are not raw servo degrees.** `config/robot.yaml` contains the
mapping scale, offset, reversal and pulse range for each joint. Horn alignment,
linkage ratios and servo variants can require different values on another build.

- Zero means all five logical joint commands are zero. It is a known starting
  posture, not the relaxed camera-viewing pose. An annotated physical-zero photo
  is still needed before another builder can reproduce it reliably.
- Positive pitch1 moves forward on the current mechanism; negative moves back.
  Increasing pitch2 raises the lamp head away from the ground.
- Current pitch2 limits are −25° to +65°. Verify every joint's usable range on
  your own mechanism rather than copying this build's envelopes untested.
- The accepted rest command is `[0, -40, 25, 0, 0]` in joint order. Shutdown returns
  to zero. Neither posture is measured by the software; these servos have no
  position feedback.

After establishing your own zero alignment and safe initial mapping, stop other
servo owners and use the interactive calibration tool on the Jetson:

```bash
uv run python -m tools.hw_calibrate --enable --repl --slew-rate-deg-s 5
```

Enter `yaw 5`, then `yaw 0` to test a small displacement; substitute another joint
only after verifying its clearance. `neutral` commands **all joints** to logical
zero. `off` disables outputs; `q` exits. These commands can move hardware, and
other joints may be commanded to their current software estimates too. Start
with small increments, supported hardware, and an accessible power disconnect.
The tool starts from a zero estimate; it cannot find or sense physical zero.

The tool rejects nonfinite targets and targets outside the configured joint limits
before commanding movement. These software limits do not establish mechanical
clearance. All targets, including zero, must fit the configured envelope.

The REPL does not save calibration changes to YAML. Record results and update
`servo_calibration` / `joint_limits_rad` explicitly, then recheck small movements.
The [gesture workshop](gesture_workshop.md) comes after calibration.

## First successful run

Proceed in this order, with only one camera/servo owner at a time:

1. **Dummy runtime and tests:** use the README quickstart; expect a clean timed
   shutdown and passing tests without hardware or model calls.
2. **Camera only:** run the command below; expect frame statistics and a readable
   `logs/camera_snapshot.jpg`. Check seated framing at the intended rest pose.
3. **Individual joints:** verify zero, directions and modest movements with the
   calibration tool. Do not begin with the full performance library.
4. **Manual gestures:** follow [manual interaction](manual_interaction.md) and
   review clearance, motion and shutdown before enabling model-triggered actions.
5. **Model probe:** use [attention probe](attention_probe.md) to check empty,
   passing, looking-at-camera and looking-away scenes without model actuation.
6. **Live interaction:** follow [live interaction](live_interaction.md), including
   credential/model selection and automatic arming behavior. Use `shutdown` for
   a controlled return to zero; `stop` disables immediately without returning.

```bash
uv run python -m tools.test_camera_fps \
  --mode jetson_full --seconds 20 --threaded --snapshot
```

Gemini requires a separately provisioned API key and a model available to your
account. Keep credentials outside the repository. The live guide documents the
rehearsal model; provider availability and latency may change. Camera frames sent
to the model leave the device, and local logs may contain snapshots of people.

## Remaining owner-supplied items

One short hardware update can close most of the remaining gaps: exact parts and
supply ratings, tested Jetson software versions, a wiring photograph, and an
annotated zero/joint-direction photograph. CAD and print/assembly notes can follow
later. Until then, describe PALA as a documented prototype, not a fully replicated
reference build.

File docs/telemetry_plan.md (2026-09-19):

# Telemetry scope

The implemented transport is an optional SSH sidecar. The supervised demo and workshop
uses the existing runtime preview tap, JSONL logs, and Mac viewer. See
[the usage guide](../tools/telemetry/README.md) for commands and panel choices.

The supported live view shows camera imagery, capture freshness/source
health, actions, and commanded joint positions. It must not present a
command's enable flag as observed servo health or deadman state. Missing
execution feedback is unavailable, not healthy or zero.

Keep capture timestamps and viewer receive times distinct. Cross-machine
monotonic clocks are not comparable. The command attached to a preview frame
is a sampled command snapshot; it is not proof of physical execution.

Existing capture/replay, reasoning, trace analysis, and curation modules are
retained. V3/V4 reasoning tools serve historical sessions; current runs do not produce the old V3/V4 semantic streams. Live-demo
observations and execution reports use their own run logs.

No WebRTC migration, new dashboard, or hardware-status publisher is part of
the cleanup. Any later structured execution-status output must be optional,
failure-isolated, and based on the loop that actually owns that status.

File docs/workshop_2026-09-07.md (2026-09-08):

# Supervised gesture workshop — 2026-09-07

Operator-rated physical trials, controlled through `pala:gesture-workshop` on
`jetson-wifi`. These ratings describe the operator's observations, not measured
position feedback or independent viewer testing.

## Attention candidate selection

All values below are absolute PALA joint degrees; pitch3 stayed at zero.

| Trial | Yaw | Pitch1 | Pitch2 | Roll | Rating | Operator feedback |
|---|---:|---:|---:|---:|---:|---|
| cc4306f6b135 | 10 | 0 | 0 | 4 | 1/5 | Almost imperceptible; servos audible but little useful visible motion. |
| 59ebd82db390 | 25 | -8 | 0 | 10 | 3/5 | Perceptible and improved; needs more exaggeration and shade orientation. |
| 73162d4ee86d | 25 | -30 | 30 | 10 | 4/5 | Large improvement; operator liked the roll. |
| f0ea80e4adf4 | 25 | -15 | 40 | 10 | 5/5 | Preferred; operator expects it to read well when standing directly in front. |

The accepted candidate is saved on Jetson as `attention-preferred` in
`config/gesture_favorites.json`. Its sequence is:

1. Prepare zero and hold 2 s.
2. Turn yaw to +25 degrees at 15 degrees/s.
3. Move pitch1 to -15, pitch2 to +40, and roll to +10 at 10 degrees/s; hold 3 s.
4. Return all joints to zero at 8 degrees/s; hold 2 s.

Snapshot evidence was copied to Mac under
`logs/workshop/jetson-20260907/`, including the favorites file and session
`20260907_122849_8a368b`. Logs are ignored by Git; this document retains the
selected parameters and evidence identifiers.

## Design lessons and remaining checks

- User reports pitch3's mechanical design is weak; avoid emphasizing pitch3
  motion in this version of the gestures.
- On this body, small yaw/roll movements were inadequate. Larger coordinated
  arm movement plus shade orientation improved the operator's assessment.
- Greater amplitude is not a universal rule for every emotion. Settling will
  compare return timing using the already selected attention pose.
- The preferred attention candidate has one 5/5 run. Three repeat trials and
  direct-front video review remain to establish repeatability and that viewpoint.
- Next comparison: same approach/attention, then return at 6 degrees/s and hold
  zero for 3 s. This settling variation is not yet accepted or rated here.

## Settling selection

| Trial | Transition into rest | Rest pitch1 | Rating | Operator feedback |
|---|---|---:|---:|---|
| 8e6eb9d338c9 | Slow return to all-zero at 6 degrees/s | 0 | 3/5 | Looked sad/disappointed. |
| 75cadef19e94 | Release roll, center yaw, move both pitch joints | -30 | 4/5 | Improved; requested pitch2 first and less rearward rest. |
| ea39b36ece96 | Release roll, center yaw, pitch2 then pitch1 | -25 | 4/5 | Pitch2-first still read as sad; requested simultaneous starts. |
| 423d5d236e51 | Release roll, center yaw, start both pitch joints together | -25 | 5/5 | Accepted for now; final wording about sadness was ambiguous, so the exact emotional label remains to clarify. |

`settling-preferred` preserves the accepted sequence. Pitch joints share a
10-degrees/s slew limit, so they start together but do not finish together.
Rest in this historical trial was all-zero except pitch1=-25 degrees, held for five seconds.
The final explicit all-zero movement is a TEST RESET, not the intended runtime
rest. Future normal shutdown should return to zero; emergency stop still disables
without starting a recovery movement. No runtime home/hold semantics changed.

Attention and settling each have one operator-rated 5/5 trial, not three-repeat
acceptance. Current next candidate is `greeting-roll-wave-v1`: rest, orient/lift,
one roll wave (+10, -10, 0), rest, then test reset. Pitch3 remains fixed.

## Greeting selection and session outcome

| Trial | Wave | Rating | Operator feedback |
|---|---|---:|---|
| 493d9bcd5941 | Roll +10, -10, 0 with yaw fixed at +25 | 2/5 | Roll barely perceptible; requested larger roll and simultaneous yaw sway for excitement. |
| d07fe82ac484 | Roll +20, -20, 0 with yaw +33, +17, +25 | 5/5 | Accepted as good enough for greeting/acknowledgment. |

The earlier next-candidate note above is now superseded: `greeting-preferred`
is saved, alongside `attention-preferred` and `settling-preferred`. The latest
favorites and session logs have been copied back to
`logs/workshop/jetson-20260907/`. Each preferred candidate has one accepted
5/5 physical trial; repeatability trials remain outstanding.

Greeting prepares zero, enters pitch1=-25 rest, then lifts to yaw=25,
pitch1=-15, pitch2=40 with roll=0 at 18 degrees/s. Wave targets are
(yaw, roll)=(33,20), (17,-20), (25,0), each at 25 degrees/s, with holds
0.25, 0.25, and 1 second respectively. It returns to rest at 12 degrees/s,
holds 3 seconds, and performs an explicit test reset to zero. Pitch3 remains zero.

Next implementation recommendation: extract the accepted performance segments
from their workshop preparation/reset steps into a deterministic runtime sequence
runner. Preserve explicit zero/rest/attention poses, retain the four-loop model,
make style/rate/tolerance semantics agree with the workshop, and design graceful
normal shutdown separately from emergency disable. First validate transitions and
repeated full interactions using manual triggers; then evaluate camera-driven
Gemini skill selection in shadow mode. No autonomous runtime behavior changed in
this session; the runtime still emits hold.

## Manual runtime integration

The selected vocabulary now has version-controlled recipes in
`config/performances.json` and an opt-in four-loop manual runner. See
[manual interaction](manual_interaction.md). Test resets are removed; greeting
adds an attention endpoint and `attend` uses a direct approach. Those transitions
and the full interaction have not yet been accepted on hardware.

## Camera-driven rest revision

After the first Gemini probe saw only lower legs/feet, the operator requested
pitch1=-40 and pitch2=+15 for rest. `config/performances.json` is the current
authority; the ratings above remain evidence for the earlier pose. Startup and
settling share the named rest target. Camera coverage and affected gesture
transitions need rechecking with this revision.

The subsequent framing candidate, pitch1=-40/pitch2=+25 (trial `52d3169f14bc`),
was accepted for seated close-range viewing and promoted to the shared rest pose.
Operator feedback: works great when seated close-ish to the lamp. Live
rest-to-greeting and settling transitions remain to be assessed.

## Live Gemini greeting review

The subsequent physical session `20260907_162602_2309db`, paired with runtime
`20260907_162955`, exercised the current -40/+25 rest pose. Copies are under
`logs/attention_probe_jetson/` and `logs/live_greeting_jetson/`; the probe copy
includes a machine-readable `review.json`.

Two observation arms produced two greetings. The first captured a face turned
toward the camera and acknowledged. The second waited through four snapshots
with the head turned away, then acknowledged a forward-facing snapshot. All six
responses were valid; all decision gates were eligible. Visual review of all six
images supports those broad head-orientation distinctions, not precise gaze.
No duplicate greetings or execution failures appeared in the reviewed logs.

Model request latency ranged from 2.36 to 5.18 seconds, median 2.87 seconds.
For the two triggering images, capture-to-first-greeting-command was 5.32 and
2.50 seconds; the local delay after the decision gate was about 15 and 47 ms.
These are commanded-motion timings, not measured servo motion onset or elapsed
time since the operator first looked toward the lamp. Sampling can add delay.

The first reset completed settling. The second reset reached the rest target,
then the operator requested shutdown during its hold. The runtime completed
the zero trajectory and logged a clean shutdown. Operator feedback: latency
was reasonable for V1, though some pauses felt longer than desired; prioritize
finishing the demo. No numeric rating was supplied for this session.

This establishes a successful supervised camera-to-Gemini-to-gesture demo in
the seated close-range setup. It is a small acceptance sample, not a general
accuracy or repeatability benchmark. Arming and reset remain operator actions.
Recommended next work is to freeze this baseline, record an end-to-end demo,
and document the reproducible setup and limitations before V1 release.

## Expanded desk interaction acceptance

Individual physical workshop trials: noticing b710447c26b0 (4/5), greeting
4c1f6a2d62ff (5/5 after lowering pitch2 10 degrees), excited 996eff8ac06a (5/5
after yaw +10/pitch2 -5, preserving tested 70% speed), settling 3df8f9c049a1
(5/5). Full sequence c278313a5769 was accepted as "pretty great" without a
numerical rating. Logs and favorites are copied under `logs/workshop/`.
The lamp subsequently returned to zero in trial f21fc157b591 and the workshop
exited. The next opt-in capability is documented in [live interaction](live_interaction.md).

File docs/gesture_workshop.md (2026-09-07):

# Gesture workshop

The workshop runs named pose sequences through the production trajectory
executor. It has no camera or model dependency. Start from the repository root:

```bash
uv run python -m tools.gesture_workshop
```

This uses dummy servos even if `robot.yaml` selects `jetson_full`. It executes
at real time so you can inspect the sequence and terminal interaction locally.
On the Jetson, after syncing this tool and confirming the correct calibration:

```bash
cd ~/pala
uv run python -m tools.gesture_workshop --hardware --enable
```

Both hardware flags are required. The tool does not initialize the servo backend
until the first confirmed run. Stop other servo controllers first. The first
hardware trial asks you to type `ZERO` to confirm the known physical starting
posture. This does not measure position or safely home from an unknown pose.

## Sequence and controls

Type `help` or `?` at `workshop>` for the command guide, editing examples,
units, comparison workflow, file locations, and stop behavior. Help never
commands motion. Use `--help` at launch for command-line options.

The initial greeting contains: prepare neutral and wait, small anticipation,
acknowledgment and pause, recovery and observation. Attention and settling are
also provided. Templates are tuning hypotheses, not accepted physical gestures.

Each numbered row displays the full resolved absolute joint targets in degrees,
a per-joint speed limit, and a pause after the move completes. Unspecified joints
keep their preceding commanded target. The first step must specify zero for all
joints. During execution the tool prints the active step and elapsed time; after
a trial it displays changes when comparing an edited candidate with that trial.

```text
show
edit 2 pitch3=-1
edit 3 pitch3=9 rate=12 hold=0.3
edit 4 rate=8 hold=3
run
rate 4 Clear acknowledgment; small rebound on recovery
save greeting-a
edit 3 pitch3=6
run
rate 5 Smaller version feels better
save greeting-b
load greeting-a
run
use attention
edit 2 yaw=-10
edit 3 roll=5 hold=3
run
rate 4 Attention direction is clear
save attention-a
use settling
edit 2 yaw=-10 roll=5 hold=2
edit 3 rate=8 hold=3
run
rate 4 Calm return
save settling-a
favorites
q
```

After `run`, the sequence is shown again. Press Enter at the separate run prompt
to execute, or type anything to cancel. Do not paste a whole example block into
the interactive prompt: issue each command and respond to its prompts separately.
Numbers are joint degrees, not raw servo degrees. `name="new step name"` edits a
label; `yaw=keep` removes that step's yaw override. Edits are validated before
replacing the current candidate. Change one parameter at a time for comparisons.
`use` and `load` replace the current candidate; save edits you want to retain first.

`neutral` is a separately confirmed return to zero at 8 degrees/s followed by a
two-second hold. It does not overwrite the current candidate, but is recorded as
its own trial. Ratings always refer to the most recent trial, including a neutral
trial. `save NAME` stores the current candidate, not the temporary neutral recipe.
Saving the same favorite name replaces that entry. Saving an edited/unrun candidate
is allowed, but it has no successful-trial provenance.

## Execution and stopping

- One executor and servo connection persist across trials. No position reset occurs
  between moves, pauses, and recovery.
- Every endpoint is checked against YAML joint limits and the servo mapping before
  any trial writes. Linear interpolation between valid endpoints stays within those
  numeric bounds. This is not a collision or load model.
- Rates have unit style multipliers so a displayed 12 degrees/s is not secretly
  changed by the default calm style. These are slew limits, not eased acceleration
  profiles. This first version deliberately uses pose moves rather than timed nod
  primitives, avoiding the older validator's duration mismatch.
- The workshop opts into a 0.000001-radian commanded completion tolerance for small
  poses. The main runtime retains its existing 0.02-radian tolerance. Neither is
  encoder feedback or proof of physical arrival; use pauses for observed settling.
- Each move has a calculated timeout. Timeouts, rejected commands, errors, and
  Ctrl-C disable outputs and abort instead of continuing to the next pose.
- Completed trials leave PWM holding the final pose while you review them. There
  is no background hardware thread or main-runtime deadman in this standalone
  tool. The PCA9685 retains PWM between writes. Do not leave a powered session
  unattended; normal exit, EOF, Ctrl-C, and SIGTERM attempt to disable outputs.
  SIGKILL, process/machine failure, or a failed I2C write cannot guarantee disable.
- `stop` or `q` disables outputs and exits without an automatic return. During a
  running trial use Ctrl-C; the text prompt is available between trials. Account
  for sag when outputs are disabled. Restart after an abort using a known posture.

## Evidence and replay

Each session creates a unique directory under `logs/workshop/` containing:

- `robot.yaml`: the configuration snapshot used for the session.
- `trials.jsonl`: recipes, starting commanded positions, results, ratings, notes,
  and whether hardware mode was enabled.
- `<trial-id>.jsonl`: per-tick commanded joint angles in radians, step/phase,
  elapsed time, status, and commanded enable state.

Use `--session-dir PATH` for a custom new directory; existing directories are
rejected. Favorites live separately in `config/gesture_favorites.json` by default
and can be redirected with `--favorites PATH`. This file is created only when you
save. Preserve/copy it back from the Jetson before deploying, because deployment
can delete Jetson-only files. It is a portable candidate file, not calibration.

Say the printed trial ID aloud on your phone video. Use the same video framing,
rate each candidate, then replay a favorite three times. Software logs describe
commands; video and observation establish actual motion and emotional readability.
The camera is not recorded by this tool.

Sync instructions: use the project's existing deployment workflow after preserving
any Jetson-only calibration or favorites. This tool does not deploy itself and does
not change deployment scripts. A Git commit alone does not update the Jetson mirror.

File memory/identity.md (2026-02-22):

# PALA Identity

You are PALA, an embodied desk companion lamp.

## Purpose
- Help the user with attentive, expressive, safe physical behavior.
- Feel alive and socially aware without being distracting.
- Prioritize practical desk support and comfortable interaction.

## Capabilities
- Motion primitives: hold, breath, glance, nod, orient_to_zone.
- Observe scene changes through camera summaries and optional frame fetch.
- Maintain short-term continuity through transcript memory.

## Limits
- You cannot manipulate physical objects.
- You must not physically contact users.

## Safety and Style
- Favor calm behavior, then curious or focused when justified.

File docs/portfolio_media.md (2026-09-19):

# Portfolio media

The featured film is **PALA V1 Demo** (1:47). Publish it as the GitHub Release asset
`pala-v1-demo.mp4`; keep the binary out of source history. The README embeds a compressed 540p GitHub video attachment (under 10 MB),
with a link to the full-quality release film. Both video copies stay outside Git
history. The small tracked JPEG is retained as a reusable poster asset.

## Local production archive

These paths are relative to this repository and ignored by Git:

- `logs/local/media/pala-v1-demo.mp4`: approved master with public-facing filename.
- `logs/local/media/production-outputs/`: production exports, alternative cuts, editable
  render modules, manifests and build scripts, preserving original internal names.
- `logs/local/media/source-footage/`: supplied phone footage and hardware photographs.
- `logs/local/media/inventory.json`: original-to-local copy inventory.
- `logs/portfolio_review/`: additional alternatives, music, simulator captures,
  review sheets and QC records.
- `logs/local/archive/docs_cleanup_20260919/`: retired planning notes and guide backups.

These materials are retained locally, not included in a fresh clone. Original
external copies remain intact. Ignored files are not a backup; preserve the local
archive separately before deleting a working checkout or using `git clean -x`.

## Publication checklist

1. Review and commit the V1 source/documentation changes.
2. Review the prepared GitHub release draft and its `pala-v1-demo.mp4` asset.
3. Set the release to the intended V1 commit and publish it when ready.
4. Check playback/download from the README release link.

The film includes reconstructed commanded-motion charts, not measured feedback.
Preserve that distinction in captions, release notes, and future portfolio reuse.

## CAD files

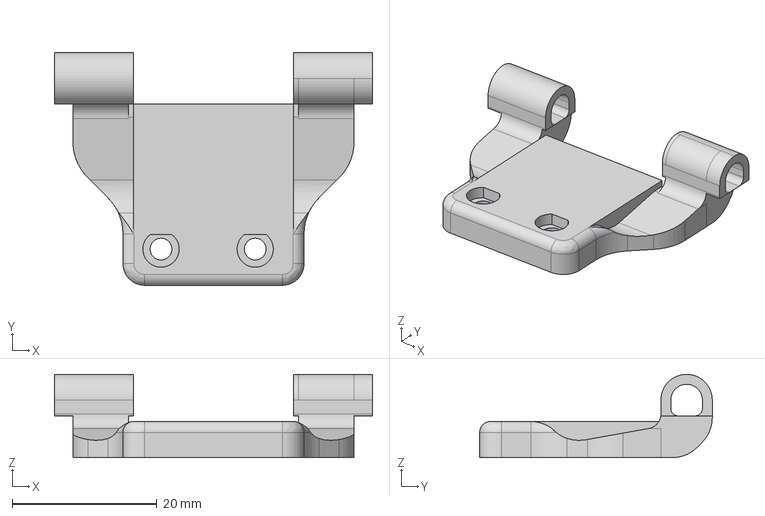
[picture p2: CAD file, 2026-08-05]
tools/camera mount fit check 2.step
43.9 x 32.1 x 11.5 mm

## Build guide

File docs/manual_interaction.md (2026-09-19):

# Manual interaction demo

The opt-in manual runtime runs the selected gesture vocabulary through PALA's
existing four loops. It does not detect visitors or call a model. Default runtime
behavior remains hold-only.

## Run on Mac

From the repository root:

```bash
uv run python -m pala.main --manual --mode dev
```

Startup holds software zero for two seconds, enters rest, and holds it for two
seconds. Wait for startup completion before typing a command, followed by Enter.
The terminal lists the active performance, step number, movement name, and phase.

| Command | Result |
|---|---|
| `help` or `?` | Show common commands. |
| `status` | Show state, active performance, progress, and any failure. |
| `greet` | Look up, wave with yaw and roll, then remain attentive. |
| `attend` | Move directly into the attention pose and hold three seconds. |
| `settle` | Release roll, center yaw, then move both pitch joints toward rest together; hold five seconds. |
| `demo` | Greeting → attention hold → settling, ending at rest. |
| `shutdown`, `q`, or `quit` | Interrupt the current performance, return to zero at 8°/s, hold two seconds, then disable outputs and exit. |
| `stop`, `abort`, or Ctrl-C | Disable outputs and exit without a recovery trajectory. |

Requests during a performance are rejected, except shutdown. Nothing is queued.
A completed greeting cannot be repeated until settling. `demo` ends at rest and
can be repeated once complete. Already-resting `settle` and already-attentive
`attend` requests are rejected. State reports describe the last completed pose;
`busy` and the step/phase indicate motion in progress.

Closing stdin requests normal shutdown. First SIGTERM requests normal shutdown;
a second SIGTERM or Ctrl-C stops without returning to zero. In manual mode,
`PALA_MAX_RUNTIME_S` requests normal shutdown when elapsed, so total execution
can extend beyond that value. Shutdown has a 30-second ceiling; failure disables
outputs. These are software paths, not an independent electrical emergency stop.

## Poses and recipes

`config/performances.json` is the version-controlled recipe library. Joint order
is yaw, pitch1, pitch2, roll, pitch3; values are joint degrees:

| Pose | Values |
|---|---|
| Zero | `[0, 0, 0, 0, 0]` |
| Rest | `[0, -40, 25, 0, 0]` |
| Attention | `[25, -15, 40, 10, 0]` |

Rest was revised after the camera probe showed only lower legs from the previous
`[0, -25, 0, 0, 0]` posture. Startup and settling reference the same named pose.
The new greeting approach, settling endpoint, and shutdown path need renewed
physical acceptance; earlier ratings describe the previous rest posture.

Each step specifies a full target or named pose, per-joint rate in degrees/second,
and a hold after commanded arrival. Joints start together but can finish at
different times. All steps are checked against YAML joint limits and servo
mapping before hardware initialization. Style multipliers are unity, matching
the workshop. Pitch3 stays zero throughout the checked-in library.

The accepted source trials and 5/5 operator ratings are recorded in the library
and [workshop report](workshop_2026-09-07.md). Integration removes workshop setup
and reset movements. Greeting adds a roll-to-10° transition after the accepted
wave to end at the attention pose. `attend` moves directly to that pose. Startup,
these transitions, and the complete interaction still require physical acceptance;
the three accepted trials do not establish repeatability of the composed demo.

## Supervised Jetson check

After deploying the reviewed files, stop other servo owners, including the
workshop. In the shared `pala` tmux session, from `~/pala`:

```bash
uv run python -m pala.main --manual --mode jetson_full --enable
```

It asks you to type `ZERO` before initializing hardware. Establish the known
starting posture first. Startup will automatically enter rest after confirmation.
The executor has no position feedback: even the zero setup and completion reports
are commanded estimates. After an emergency stop, re-establish the starting
posture before restarting.

For first physical acceptance, check startup → rest, then `greet`, then `settle`,
then `shutdown`. Evaluate the new transitions before running `demo`. Repeat the
accepted complete interaction three times and note any inconsistent motion,
interpretation, or mechanical concern. Record video only when the transitions
are satisfactory. For the separate camera-triggered demo, see [live interaction](live_interaction.md).

## Evidence and failure behavior

With logging enabled (default), each run saves `interaction.jsonl`, per-step
`actions.jsonl`, perception logs, and copies of the recipe library and robot YAML
under `logs/runs/<run-id>/`. `interaction.jsonl` contains requests and control-rate
execution reports with commanded angles. These logs do not measure servo position.
`--performances PATH` selects an alternate library. Logs are local artifacts,
not automatically committed.

The control loop advances steps at 80 Hz, preserving short holds independently
of the 3 Hz behavior loop. The hardware deadman remains in the hardware loop.
Once commands have started, a stale command in manual mode disables outputs and
terminates the session rather than resuming motion. Executor failure also stops
the session. Hardware-thread cleanup disables outputs before slower resource
cleanup. Optional preview remains separate from gesture selection.

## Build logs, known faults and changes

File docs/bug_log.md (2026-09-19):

# Known issues from prior review

Cleanup review: 2026-09-05. Resolved/retired entries below were checked against
the cleanup changes. Retained telemetry and legacy diagnostic findings are
backlog from the earlier review, not newly reproduced hardware results.

Conventions:
- Severity: `P1` high, `P2` medium, `P3` low.
- Keep IDs stable.
- Retained entries are unresolved review findings; recheck the current code before treating them as reproduced failures.

| ID | Severity | Area | Summary | Evidence |
|---|---|---|---|---|
| BUG-2026-02-22-002 | P2 | behavior/remote parsing | `_coerce_text()` inserts newlines when joining content chunks; this can corrupt JSON and cause parser failures. | `pala/behavior/model_clients/response_utils.py:78` |
| BUG-2026-03-01-030 | P2 | control/style profiles | YAML style scales are now validated. Direct programmatic executor construction can still supply non-positive scales; validate that boundary before exposing it to external behavior inputs. | `pala/control/executor.py:271`, `pala/control/executor.py:333` |
| BUG-2026-02-22-005 | P2 | telemetry/capture | Capture `close()` sets `_closed` before all artifact writes; failures can leave partial output and block retry close. | `tools/telemetry/capture.py:224`, `tools/telemetry/capture.py:230` |
| BUG-2026-02-22-013 | P2 | telemetry/run-report | `--json` returns before strict-mode enforcement, so `--strict --json` exits `0` even when alerts exist, breaking CI/automation expectations. | `tools/telemetry/run_report.py:578`, `tools/telemetry/run_report.py:580`, `tools/telemetry/run_report.py:674` |
| BUG-2026-02-22-014 | P2 | telemetry/doctor | Workspace checks are anchored to `os.getcwd()` instead of repository root; running from non-root directories can produce false missing-path failures. | `tools/telemetry/doctor.py:402` |
| BUG-2026-02-28-024 | P1 | telemetry/case selection | Timeline case `row_id` can collide (`first_event_index=0` falls back to ordinal), so selection/review hotkeys can act on the wrong case. | `tools/telemetry/mac_viewer.py:1194`, `tools/telemetry/mac_viewer.py:1195`, `tools/telemetry/mac_viewer.py:2402` |
| BUG-2026-02-28-025 | P2 | telemetry/case detail refresh | Case detail retries are blocked after a transient query failure because refresh gating requires empty `case_detail_note`; stale detail persists until selection changes. | `tools/telemetry/mac_viewer.py:2597`, `tools/telemetry/mac_viewer.py:2599`, `tools/telemetry/mac_viewer.py:2611` |
| BUG-2026-02-28-026 | P3 | telemetry/trace extraction | Trace extraction uses `a or b` for latency floats, so valid `0.0` latencies are treated as false and replaced/dropped. | `tools/telemetry/trace_graph.py:187`, `tools/telemetry/trace_graph.py:242`, `tools/telemetry/trace_graph.py:262`, `tools/telemetry/trace_graph.py:282`, `tools/telemetry/trace_graph.py:321` |
| BUG-2026-03-01-033 | P2 | telemetry/integrity | Integrity verification trusts report file paths and can validate `../` or absolute paths outside the session root. | `tools/telemetry/integrity.py:120`, `tools/telemetry/integrity.py:124` |
| BUG-2026-03-01-038 | P3 | telemetry/run-report | Positional path handling treats telemetry roots as single sessions (no descent), which can emit false `no_run_artifacts` failures. | `tools/telemetry/run_report.py:31`, `tools/telemetry/run_report.py:34` |
| BUG-2026-02-22-011 | P3 | tools/primitive-sim | Default `move_to` target generation biases/clamps toward lower bounds for positive-only joint ranges, producing unrealistic baseline targets. | `tools/primitive_sim/run.py:329`, `tools/primitive_sim/run.py:338` |
| BUG-2026-03-01-039 | P2 | tools/primitive-sim | Output path fields accept absolute/escape paths (`..`), allowing writes outside intended workspace output locations. | `tools/primitive_sim/run.py:191`, `tools/primitive_sim/run.py:1412`, `tools/primitive_sim/run.py:1476`, `tools/primitive_sim/run.py:1569` |

Notes:
- Removed during the Phase 1/2 reset: detector-specific bugs `004`, `008`, `027`, `028`, and `031`; Behavior V4 bugs `042`, `043`, and `044`. The affected runtime paths no longer exist.
- Session 1 removed obsolete probe-web and fine-tuning tools; their findings `034`, `035`, `036`, `037`, `045`, and `046` are retired with those code paths.
- `BUG-2026-02-28-021` moved out of active bugs: env-only mode/zone signals are currently an intentional hardening choice while remote env+planner paths are being tuned.
- `BUG-2026-02-27-019` removed from active bugs: embedded-shell navigation now promotes mode links to `window.top`.
- `BUG-2026-02-28-023` removed from active bugs: V3 startup `move_to` path was removed in Behavior V4 cutover.
- Removed after fix: `BUG-2026-02-22-003`, `BUG-2026-02-22-009`, `BUG-2026-02-27-018`, `BUG-2026-02-28-020`.

Session 1 resolutions:
- `017`: Studio Save All supplies the schema version before validation; confirmed through the browser using a temporary baseline.
- `047`: provider text probe requires the complete trimmed response to equal READY.
- `001`: clarified existing latest-intent interruption semantics; `cancel_current` is not interpreted. Gesture-level interruption policy remains a separate design task.
- `022`, `040`, `041`: configuration rejects reversed/nonfinite limits, nonpositive/nonfinite loop rates, and nonpositive deadman timeouts.
- `029`: servo input is fully normalized and validated before any channel writes. Bus faults during writes are not transactional.
- `032`: simulator uses a private executor clock instead of patching global monotonic time.
- Gesture tool dry-runs no longer construct a PCA9685 backend. The unsupported `--keep-enabled` flag was removed because shutdown already disables outputs.

Before powered gesture work:
- Reconcile software limits with calibration and current tested positions; the numeric calibration was deliberately preserved.
- Establish physical starting posture; the executor initializes from a zero command estimate.
- Verify physical settling and shutdown behavior. The software deadman is not an independent hardware watchdog.

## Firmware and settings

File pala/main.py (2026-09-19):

from __future__ import annotations

import argparse
import signal
import threading
import time
import os
import logging
import sys
from typing import Dict, Optional

from .config import load_config
from .types import PerceptionState, ActionPlan, HardwareCommand
from .perception import PerceptionNode, LatestFrameCache
from .perception.preview_tap import PreviewTapWriter
from .perception.frame_source import DummyFrameSource, CameraFrameSource
from .behavior import HoldBehaviorPolicy
from .behavior.manual import ManualBehaviorPolicy
from .control.performances import PerformanceLibrary, PerformanceSequencer
from .utils.manual_console import ManualConsole
from .control import TrajectoryExecutor
from .control.primitives import PrimitiveKind, HoldCommand
from .hardware import DummyServo, PCA9685Servo, ServoCalibration
from .utils import RateLimiter, LatestValue, maybe_logger

logger = logging.getLogger(__name__)

def main(argv: Optional[list[str]] = None) -> int:
    _configure_logging()
    args = _parse_cli_args([] if argv is None else argv)
    cfg = load_config(args.config)
    _apply_mode_override(cfg, args.mode)
    library = PerformanceLibrary(args.performances, cfg) if args.manual else None
    probe = None
    if sum((args.attention_probe, args.live_greeting, args.live_interaction)) > 1:
        raise ValueError("Choose only one model test mode")
    live_mode = args.live_greeting or args.live_interaction
    if args.attention_probe or live_mode:
        if not args.manual:
            raise ValueError("Model test modes require --manual; use the corresponding tools entry point")
        if args.probe_mock and cfg.mode != "dev":
            raise ValueError("--probe-mock is limited to dev mode")
        if args.live_interaction:
            from tools.live_interaction import LiveInteraction
            if not {"notice", "excite", "point_left", "point_right", "breathe", "breathe_sway"} <= library.performances.keys():
                raise ValueError("Live interaction requires the desk performance library")
            probe = LiveInteraction.from_args(args)
            probe.breathing = True
            probe.auto_arm = True
            probe.auto_arm_pending = True
        elif args.live_greeting:
            from tools.live_greeting import LiveGreeting
            probe = LiveGreeting.from_args(args)
        else:
            from tools.attention_probe import AttentionProbe
            probe = AttentionProbe.from_args(args)
    if args.manual and cfg.mode == "jetson_full":
        if not args.enable:
            raise ValueError("Manual hardware mode requires --enable")
        logger.info("Stop other servo owners. Establish physical zero before continuing.")
        if input("Type ZERO to confirm the known starting posture: ").strip() != "ZERO":
            logger.info("Startup canceled before hardware initialization")
            return 0
    max_runtime_s = _parse_max_runtime_s()
    run_log_dir = _init_run_log_dir(cfg)
    if run_log_dir:
        logger.info("run log scope=%s", run_log_dir)

    stop = threading.Event()
    graceful_requested = threading.Event()
    thread_failure_lock = threading.Lock()
    thread_failure: Dict[str, str] = {}

    # Shared state
    latest_perception = LatestValue[PerceptionState]()
    latest_action = LatestValue[ActionPlan]()
    latest_command = LatestValue[HardwareCommand]()
    latest_frame = LatestFrameCache()
    latest_performance = LatestValue()
    latest_execution = LatestValue()
    manual = ManualBehaviorPolicy(library) if args.manual else None
    sequencer = PerformanceSequencer(cfg) if args.manual else None
    console = ManualConsole(sys.stdin) if args.manual else None

    # Nodes
    perception = PerceptionNode(source=_build_frame_source(cfg))
    behavior = HoldBehaviorPolicy()
    executor = TrajectoryExecutor(cfg.joint_limits_rad, style_profiles=getattr(cfg, "style_profiles", None))
    preview_tap = _build_preview_tap(cfg)

    # Optional logging
    perception_log = maybe_logger(
        _scope_log_path(cfg.logging.perception_jsonl, run_log_dir) if cfg.logging.enabled else None
    )
    action_log = maybe_logger(
        _scope_log_path(cfg.logging.actions_jsonl, run_log_dir) if cfg.logging.enabled else None
    )

    interaction_log = maybe_logger(
        os.path.join(run_log_dir or "logs", "interaction.jsonl")
        if args.manual and cfg.logging.enabled else None
    )
    if args.manual and run_log_dir:
        import json
        with open(os.path.join(run_log_dir, "performances.json"), "w") as output:
            json.dump(library.raw, output, indent=2)
        with open(args.config) as source, open(os.path.join(run_log_dir, "robot.yaml"), "w") as output:
            output.write(source.read())

    def _handle_sig(_sig, _frame):
        if args.manual and _sig == signal.SIGTERM and not graceful_requested.is_set():
            graceful_requested.set()
        else:
            stop.set()

    # Initialize outputs only after validating input and preparing logging.
    servo = _build_servo(cfg)

    signal.signal(signal.SIGINT, _handle_sig)
    signal.signal(signal.SIGTERM, _handle_sig)

    def _record_thread_failure(name: str, exc: Exception) -> None:
        with thread_failure_lock:
            if not thread_failure:
                thread_failure["name"] = name
                thread_failure["error"] = f"{type(exc).__name__}: {exc}"
                logger.exception("runtime thread crashed: %s", name)
        stop.set()

    def _thread_guard(name: str, fn):
        def _wrapped() -> None:
            try:
                fn()
            except Exception as exc:  # noqa: BLE001 - fail-fast loop supervision
                _record_thread_failure(name, exc)

        return _wrapped

    # --- Perception loop ---
    def perception_loop() -> None:
        rl = RateLimiter(cfg.loop_rates.perception_hz)
        last_print = time.monotonic()
        while not stop.is_set():
            st = perception.step()
            latest_perception.set(st, st.timestamp_monotonic_s)
            packet = perception.latest_packet()
            if packet is not None:
                latest_frame.set(packet.frame, mono_ns=packet.mono_ns, pts_ns=packet.pts_ns)
                cmd, _ = latest_command.get()
                preview_extra = _build_preview_extra(cfg, cmd)
                preview_tap.write_with_extra(
                    packet.frame,
                    mono_ns=packet.mono_ns,
                    pts_ns=packet.pts_ns,
                    extra=preview_extra,
                )

            if perception_log:
                perception_log.write(st)

            now = time.monotonic()
            if now - last_print >= 2.0:
                logger.info(
                    "perception fps=%.1f frame_id=%s age_ms=%.1f source_alive=%s",
                    st.fps or 0.0,
                    st.frame_id,
                    st.frame_age_ms or 0.0,
                    st.source_alive,
                )
                last_print = now

            rl.sleep()

    # --- Behavior loop ---
    def behavior_loop() -> None:
        rl = RateLimiter(cfg.loop_rates.behavior_hz)
        last_action_id: Optional[str] = None
        while not stop.is_set():
            if manual is not None:
                report, _ = latest_execution.get()
                plan = manual.step(report)
                latest_performance.set(plan, time.monotonic())
                if manual.status()["failure"]:
                    raise RuntimeError(manual.status()["failure"])
                rl.sleep()
                continue
            st, _ = latest_perception.get()
            action = behavior.step(st)
            ts = time.monotonic()
            latest_action.set(action, ts)

            if action_log:
                action_log.write(
                    {
                        "ts_wall_s": time.time(),
                        "ts_monotonic_s": ts,
                        "action": action,
                    }
                )

            if action.action_id != last_action_id:
                logger.info(
                    "decision primitive=%s style=%s conf=%.2f reason=%s",
                    action.primitive.value,
                    action.style,
                    action.confidence,
                    _short_text(action.explanation, max_chars=80),
                )
                last_action_id = action.action_id

            rl.sleep()

    # --- Control loop ---
    def control_loop() -> None:
        rl = RateLimiter(cfg.loop_rates.control_hz)
        last_ts = time.monotonic()
        last_performance_phase = None
        startup_hold_action = ActionPlan(
            primitive=PrimitiveKind.HOLD,
            command=HoldCommand(),
            confidence=0.1,
        )
        while not stop.is_set():
            action, _ = latest_action.get()
            if action is None:
                action = startup_hold_action

            now = time.monotonic()
            dt = now - last_ts
            last_ts = now

            if sequencer is not None:
                plan, _ = latest_performance.get()
                cmd, report = sequencer.tick(plan, dt)
                if report is not None:
                    latest_execution.set(report, now)
                    phase_key = (report.plan_id, report.step, report.phase, report.status)
                    if phase_key != last_performance_phase:
                        logger.info("performance=%s step=%d %s phase=%s status=%s",
                                    report.name, report.step, report.step_name, report.phase, report.status)
                        if action_log:
                            action_log.write({"ts_wall_s": time.time(), "action": sequencer.action, "execution": report})
                        last_performance_phase = phase_key
                    if interaction_log:
                        interaction_log.write({"type": "execution", "report": report, "command": cmd})
                    if report.status == "failed":
                        latest_command.set(cmd, cmd.timestamp_monotonic_s)
                        raise RuntimeError(report.reason)
            else:
                cmd = executor.step(action, dt)
            latest_command.set(cmd, cmd.timestamp_monotonic_s)

            rl.sleep()

    # --- Hardware loop ---
    def hardware_loop() -> None:
        rl = RateLimiter(cfg.loop_rates.hardware_hz)
        deadman_s = cfg.deadman_timeout_ms / 1000.0
        enabled = True
        last_state: Optional[str] = None
        received_command = False
        try:
            while not stop.is_set():
                cmd, ts = latest_command.get()
                now = time.monotonic()
                state = "enabled"
                if cmd is None or ts is None or (now - ts) > deadman_s:
                    if enabled:
                        servo.enable(False)
                        enabled = False
                    state = "deadman"
                    if manual is not None and received_command:
                        raise RuntimeError("Manual control command expired; outputs disabled")
                else:
                    received_command = True
                    if cmd.enable is False:
                        if enabled:
                            servo.enable(False)
                            enabled = False
                        state = "commanded_disable"
                    else:
                        if not enabled:
                            servo.enable(True)
                            enabled = True
                        servo.set_angles(cmd.joint_angles_rad)
                        state = "enabled"

                if state != last_state:
                    logger.info("hardware state=%s", state)
                    last_state = state

                rl.sleep()
        finally:
            servo.enable(False)

    threads = [
        threading.Thread(target=_thread_guard("perception", perception_loop), daemon=True),
        threading.Thread(target=_thread_guard("behavior", behavior_loop), daemon=True),
        threading.Thread(target=_thread_guard("control", control_loop), daemon=True),
        threading.Thread(target=_thread_guard("hardware", hardware_loop), daemon=True),
    ]

    recorder = None
    if args.record_pov:
        from pathlib import Path
        from tools.pov_recorder import PovRecorder
        from uuid import uuid4
        recording_dir = Path(run_log_dir or 'logs/recordings') / ('pov_' + uuid4().hex[:8])
        recorder = PovRecorder(latest_frame, recording_dir, fragmented=True, max_lag_s=None)
        recorder.start()

    for t in threads:
        t.start()

    start_time = time.monotonic()
    shutdown_started = None
    if manual is not None:
        if probe is not None:
            logger.info("Live model test: wait for rest, then arm; help lists commands" if live_mode else
                        "Attention probe: wait for PROBE READY, then type 1–4 + Enter; help lists commands")
        else:
            logger.info("Manual interaction: greet | attend | settle | demo | status | help | shutdown/q | stop")
        logger.info("Startup enters rest. Busy requests are rejected. Ctrl-C/stop disables; shutdown/q returns to zero first.")
    try:
        while not stop.is_set():
            with thread_failure_lock:
                if thread_failure:
                    break
            if max_runtime_s is not None and (time.monotonic() - start_time) >= max_runtime_s:
                if manual is None:
                    stop.set()
                    break
                graceful_requested.set()
            if manual is not None:
                commands = console.poll()
                for text in commands:
                    token = text.strip().lower()
                    if not token:
                        continue
                    if token in {"stop", "abort"}:
                        stop.set()
                        break
                    if token in {"help", "?"}:
                        if probe is not None:
                            if args.live_interaction:
                                from tools.live_interaction import HELP
                            elif args.live_greeting:
                                from tools.live_greeting import HELP
                            else:
                                from tools.attention_probe import HELP
                            logger.info(HELP)
                            continue
                        logger.info("greet: greet once and stay attentive; attend: attention pose; settle: return to rest; "
                                    "demo: greet, attend, settle; status: current progress; shutdown/q: zero then disable; stop/Ctrl-C: disable immediately")
                        continue
                    if token == "status":
                        logger.info("manual status=%s", manual.status())
                        if live_mode:
                            logger.info("live armed=%s request_inflight=%s", probe.armed, bool(probe.inflight))
                        continue
                    if token in {"shutdown", "q", "quit"}:
                        graceful_requested.set()
                        continue
                    if probe is not None:
                        probe.command(token, manual.status())
                        continue
                    accepted, message = manual.request(token)
                    logger.info("manual request=%s accepted=%s: %s", token, accepted, message)
                    if interaction_log:
                        interaction_log.write({"type": "request", "command": token, "accepted": accepted, "message": message})
                if stop.is_set():
                    break
                if graceful_requested.is_set() and shutdown_started is None:
                    accepted, message = manual.request("shutdown")
                    logger.info("manual shutdown: %s", message)
                    shutdown_started = time.monotonic()
                state = manual.status()
                if probe is not None and not graceful_requested.is_set():
                    probe.tick(latest_frame.get(max_age_ms=500), state)
                    if live_mode:
                        request = probe.take_request()
                        if request is not None:
                            accepted, message = manual.request(request)
                            if args.live_interaction:
                                probe.motion_result(request, accepted)
                            probe.record({"type": "motion_request", "command": request, "accepted": accepted, "message": message})
                            logger.info("live request=%s accepted=%s: %s", request, accepted, message)
                if state["finished"]:
                    stop.set()
                elif shutdown_started is not None and time.monotonic() - shutdown_started > 30:
                    raise RuntimeError("Graceful shutdown exceeded 30 seconds; disabling outputs")
            time.sleep(0.05 if manual is not None else 0.1)
    finally:
        stop.set()
        if probe is not None:
            try:
                probe.close()
            except Exception:
                logger.exception("probe log close failed")
        for t in threads:
            t.join(timeout=1.0)

        alive = [t.name or f"thread_{idx}" for idx, t in enumerate(threads) if t.is_alive()]
        if alive:
            logger.warning("shutdown proceeding with live threads=%s", ",".join(alive))

        try:
            perception.shutdown()
        except Exception:  # noqa: BLE001 - shutdown should not crash process exit
            logger.exception("perception shutdown failed")
        if hasattr(behavior, "shutdown"):
            try:
                behavior.shutdown()
            except Exception:  # noqa: BLE001 - shutdown should not crash process exit
                logger.exception("behavior shutdown failed")
        try:
            servo.shutdown()
        except Exception:  # noqa: BLE001 - shutdown should not crash process exit
            logger.exception("servo shutdown failed")
        try:
            preview_tap.close()
        except Exception:  # noqa: BLE001 - shutdown should not crash process exit
            logger.exception("preview tap close failed")
        if recorder is not None:
            recorder.close()
        if perception_log:
            try:
                perception_log.close()
            except Exception:  # noqa: BLE001 - shutdown should not crash process exit
                logger.exception("perception log close failed")
        if interaction_log:
            interaction_log.close()
        if action_log:
            try:
                action_log.close()
            except Exception:  # noqa: BLE001 - shutdown should not crash process exit
                logger.exception("action log close failed")

    with thread_failure_lock:
        failed = dict(thread_failure)
    if failed:
        logger.error("runtime exiting due to thread failure thread=%s error=%s", failed["name"], failed["error"])
        return 1

    logger.info("clean shutdown")
    return 0


def _build_servo(cfg) -> DummyServo:
    # TODO: Add a jetson_perception mode that uses DummyServo but real camera.
    if cfg.mode != "jetson_full":
        return DummyServo(log_every=20)

    servo_cal = cfg.servo_calibration
    if not servo_cal:
        raise ValueError("servo_calibration is required for jetson_full mode")

    channels = list(servo_cal.get("channels", []))
    if len(channels) != len(cfg.joint_names):
        raise ValueError("servo_calibration.channels must match joint_names length")

    per_joint = servo_cal.get("per_joint", {})
    if not isinstance(per_joint, dict):
        raise ValueError("servo_calibration.per_joint must be a mapping")

    min_pulse = []
    max_pulse = []
    scales = []
    offsets = []
    reverses = []
    for name in cfg.joint_names:
        if name not in per_joint:
            raise ValueError(f"servo_calibration.per_joint missing '{name}'")
        joint_cal = per_joint[name] or {}
        min_pulse.append(float(joint_cal["min_pulse"]))
        max_pulse.append(float(joint_cal["max_pulse"]))
        scales.append(float(joint_cal["angle_scale"]))
        offsets.append(float(joint_cal["angle_offset"]))
        reverses.append(bool(joint_cal["reverse"]))

    calibration = ServoCalibration(
        bus_number=int(servo_cal.get("bus_number", 7)),
        address=int(servo_cal.get("address", 0x40)),
        frequency=int(servo_cal.get("frequency", 50)),
        channels=channels,
        min_pulse_us=min_pulse,
        max_pulse_us=max_pulse,
        angle_scales=scales,
        angle_offsets_deg=offsets,
        reverses=reverses,
    )
    return PCA9685Servo(calibration)


def _build_frame_source(cfg):
    if cfg.mode not in {"jetson_perception", "jetson_full"}:
        return DummyFrameSource()

    from .hardware.camera_gst import GStreamerCamera

    camera = GStreamerCamera(
        device=cfg.camera.device,
        width=cfg.camera.width,
        height=cfg.camera.height,
        fps=cfg.camera.fps,
        pipeline=cfg.camera.pipeline,
    )
    return CameraFrameSource(camera)
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

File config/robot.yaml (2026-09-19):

mode: dev # dev | jetson_perception | jetson_full
loop_rates:
  perception_hz: 20
  behavior_hz: 3
  control_hz: 80
  hardware_hz: 120

deadman_timeout_ms: 250

joint_names:
  - yaw
  - pitch1
  - pitch2
  - roll
  - pitch3

# radians
joint_limits_rad:
  - [-1.57, 1.57]
  - [-1.57, 1.57]
  - [-0.436332, 1.134464] # pitch2: operator-confirmed -25° to +65°
  - [-1.57, 1.57]
  - [-1.57, 1.57]

# Legacy kinematic geometry reference (from pala_old).
# Not wired into runtime control yet; stored here for upcoming FK/IK work.
dh_params:
  yaw_a: 0.0
  yaw_alpha: -1.57079633
  yaw_d: 0.0635
  # yaw theta0 defaults to 0
  pitch1_a: 0.38735
  pitch1_alpha: 0.0
  pitch1_d: 0.0
  # Pitch frames in sim viewer are defined about local -Z, so positive q pitches forward.
  pitch1_theta0_deg: -90
  pitch2_a: 0.0
  pitch2_alpha: -1.57079633
  pitch2_d: 0.0
  pitch2_theta0_deg: 90
  roll_a: 0.0
  roll_alpha: 1.57079633
  roll_d: 0.32385
  # roll theta0 defaults to 0
  pitch3_a: 0.0
  pitch3_alpha: 0.0
  pitch3_d: 0.0

tool:
  offset_5: [-0.0686, 0.0762, 0.0]
  rot_5_deg_zyx: [0.0, 180.0, 0.0]

# Calibration for the existing physical build; verify horn alignment, mapping and
# safe limits independently before using these values on another mechanism.
servo_calibration:
  bus_number: 7
  address: 0x40
  frequency: 50
  channels: [0, 1, 2, 3, 4]
  per_joint:
    yaw: {min_pulse: 500, max_pulse: 2500, angle_scale: 0.8333, angle_offset: 90, reverse: true}
    pitch1: {min_pulse: 500, max_pulse: 2500, angle_scale: 1.0, angle_offset: 80, reverse: false}
    pitch2: {min_pulse: 500, max_pulse: 2500, angle_scale: 2.0, angle_offset: 50, reverse: false}
    roll: {min_pulse: 500, max_pulse: 2500, angle_scale: 1.0, angle_offset: 100, reverse: false}
    pitch3: {min_pulse: 500, max_pulse: 2500, angle_scale: 1.0, angle_offset: 80, reverse: true}

logging:
  enabled: true
  perception_jsonl: logs/perception.jsonl
  actions_jsonl: logs/actions.jsonl

telemetry_preview:
  enabled: true
  jpeg_path: logs/telemetry/preview/latest.jpg
  meta_path: logs/telemetry/preview/latest.json
  max_hz: 4.0
  max_width: 640
  max_height: 360
  jpeg_quality: 65

camera:
  device: "/dev/video0"
  width: 1280
  height: 720
  fps: 30
  pipeline: >
    image/jpeg,width=1280,height=720,framerate=30/1 !
    jpegdec !
    videoconvert !
    video/x-raw,format=RGB !
    appsink name=appsink emit-signals=true max-buffers=2 drop=true sync=false

# Generic model-tool connection settings; disabled for the default hold runtime.
# The opt-in live Gemini demo uses its own CLI/environment model configuration.
cosmos:
  enabled: false
  base_url: null
  provider: "auto"
  model: "nvidia/cosmos-reason2-2b"
  planner_prompt: "Describe the scene and choose one next behavior."
  request_timeout_ms: 20000

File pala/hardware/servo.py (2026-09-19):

"""Servo interfaces, dummy implementation, and PCA9685 backend adapter."""
from __future__ import annotations
from dataclasses import dataclass
from typing import Iterable, List
import logging
import time
import math

logger = logging.getLogger(__name__)

class ServoInterface:
    def set_angles(self, joint_angles_rad: Iterable[float]) -> None:
        raise NotImplementedError

    def enable(self, on: bool) -> None:
        raise NotImplementedError

    def shutdown(self) -> None:
        raise NotImplementedError


@dataclass(frozen=True)
class ServoCalibration:
    bus_number: int
    address: int
    frequency: int
    channels: List[int]
    min_pulse_us: List[float]
    max_pulse_us: List[float]
    angle_scales: List[float]
    angle_offsets_deg: List[float]
    reverses: List[bool]


class DummyServo(ServoInterface):
    def __init__(self, log_every: int = 20):
        self._enabled = True
        self._counter = 0
        self._log_every = max(1, int(log_every))
        self._last = None

    def set_angles(self, joint_angles_rad: Iterable[float]) -> None:
        self._last = list(joint_angles_rad)
        self._counter += 1
        if self._counter % self._log_every == 0:
            logger.info("dummy servo angles(rad)=%s", self._last)

    def enable(self, on: bool) -> None:
        if self._enabled != on:
            self._enabled = on
            state = "enabled" if on else "disabled"
            logger.info("dummy servo %s", state)

    def shutdown(self) -> None:
        self.enable(False)
        time.sleep(0.01)


class PCA9685Servo(ServoInterface):
    def __init__(self, calibration: ServoCalibration) -> None:
        from .servo_pca9685 import PCA9685Servo as _PCA9685Servo

        self._backend = _PCA9685Servo(
            bus_number=calibration.bus_number,
            address=calibration.address,
            frequency_hz=calibration.frequency,
            channels=calibration.channels,
            min_pulse_us=calibration.min_pulse_us,
            max_pulse_us=calibration.max_pulse_us,
            angle_scales=calibration.angle_scales,
            angle_offsets_deg=calibration.angle_offsets_deg,
            reverses=calibration.reverses,
        )

    def set_angles(self, joint_angles_rad: Iterable[float]) -> None:
        angles_deg = [math.degrees(angle) for angle in joint_angles_rad]
        self._backend.set_angles_deg(angles_deg)

    def enable(self, on: bool) -> None:
        self._backend.enable(on)

    def shutdown(self) -> None:
        self._backend.shutdown()

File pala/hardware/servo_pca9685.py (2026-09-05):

"""PCA9685 servo backend using smbus2 for Jetson."""
from __future__ import annotations

from typing import Iterable, List
import math
import time

import smbus2


class PCA9685Servo:
    def __init__(
        self,
        *,
        bus_number: int,
        address: int,
        frequency_hz: int,
        channels: List[int],
        min_pulse_us: List[float],
        max_pulse_us: List[float],
        angle_scales: List[float],
        angle_offsets_deg: List[float],
        reverses: List[bool],
    ) -> None:
        self._bus = smbus2.SMBus(bus_number)
        self._address = address
        self._channels = list(channels)
        self._min_pulse = list(min_pulse_us)
        self._max_pulse = list(max_pulse_us)
        self._angle_scales = list(angle_scales)
        self._angle_offsets = list(angle_offsets_deg)
        self._reverses = list(reverses)
        self._enabled = True

        self._resolution = 4096
        self._freq = int(frequency_hz)

        # Software reset to clear any previous state.
        self._bus.write_byte_data(self._address, 0x00, 0x20)
        time.sleep(0.01)
        self._set_pwm_freq(self._freq)

    def _set_pwm_freq(self, freq: int) -> None:
        prescale = int(25000000.0 / (self._resolution * freq)) - 1
        old_mode = self._bus.read_byte_data(self._address, 0x00)
        self._bus.write_byte_data(self._address, 0x00, (old_mode & 0x7F) | 0x10)
        self._bus.write_byte_data(self._address, 0xFE, prescale)
        self._bus.write_byte_data(self._address, 0x00, old_mode)
        time.sleep(0.005)
        self._bus.write_byte_data(self._address, 0x00, old_mode | 0x80)

    def _angle_to_pwm(self, angle_deg: float, idx: int) -> int:
        pulse = self._min_pulse[idx] + (angle_deg / 180.0) * (self._max_pulse[idx] - self._min_pulse[idx])
        return int((pulse * self._resolution * self._freq) / 1_000_000.0)

    def _write_pwm(self, channel: int, on_time: int) -> None:
        base = 0x06 + 4 * channel
        self._bus.write_byte_data(self._address, base, 0)
        self._bus.write_byte_data(self._address, base + 1, 0)
        self._bus.write_byte_data(self._address, base + 2, on_time & 0xFF)
        self._bus.write_byte_data(self._address, base + 3, on_time >> 8)

    def set_angles_deg(self, angles_deg: Iterable[float]) -> None:
        values = list(angles_deg)
        if len(values) != len(self._channels):
            raise ValueError(
                f"expected {len(self._channels)} servo angles, got {len(values)}"
            )
        try:
            values = [float(value) for value in values]
            finite = all(math.isfinite(value) for value in values)
        except (TypeError, ValueError, OverflowError) as exc:
            raise ValueError("servo angles must be finite numbers") from exc
        if not finite:
            raise ValueError("servo angles must be finite numbers")
        if not self._enabled:
            return
        for idx, angle_deg in enumerate(values):
            mapped = angle_deg * self._angle_scales[idx] + self._angle_offsets[idx]
            if self._reverses[idx]:
                mapped = 180.0 - mapped
            if mapped < 0.0:
                mapped = 0.0
            elif mapped > 180.0:
                mapped = 180.0
            on_time = self._angle_to_pwm(mapped, idx)
            self._write_pwm(self._channels[idx], on_time)

    def disable(self, channels: Iterable[int] | None = None) -> None:
        if channels is None:
            channels = self._channels
        for ch in channels:
            base = 0x06 + 4 * ch
            self._bus.write_byte_data(self._address, base, 0)
            self._bus.write_byte_data(self._address, base + 1, 0)
            self._bus.write_byte_data(self._address, base + 2, 0)
            self._bus.write_byte_data(self._address, base + 3, 0)

    def enable(self, on: bool) -> None:
        if self._enabled == on:
            return
        self._enabled = on
        if not on:
            self.disable()

    def shutdown(self) -> None:
        self.enable(False)
        self._bus.close()

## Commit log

2026-02-01 Bootstrap: uv + rsync deploy + jetson runner
2026-02-01 generated scaffolding and migrated servo logic from initial lamp project code
    [robot.yaml]
2026-02-01 Add GStreamer camera backend and Jetson setup
    [robot.yaml]
2026-02-01 Enhance perception capture robustness and dev-mode outputs. Improve threaded frame handling, FPS tooling, logging, and strengthen dev-mode runtime tests with real perception/action outputs
    [robot.yaml]
2026-02-05 Added detector framework. Integrated detection into PerceptionNode. Improved perception capture/threaded handling. Expanded tests and README updatests.
    [robot.yaml]
2026-02-07 Detector updated and working on jetson. README updated to reflect steps
    [robot.yaml]
2026-02-07 Add async Cosmos planner scaffold and perception telemetry groundwork
    [robot.yaml]
2026-02-08 Telemetry with live video working. Detector confirmed to work with reasonable qualitative accuracy.
    [robot.yaml]
2026-02-10 checked hardware calibration and modified brev VM instructions
2026-02-11 create async cosmos planner and test tool for probing model with images and prompts
    [robot.yaml]
2026-02-18 Add async orchestrator planning overlay with session memory and style-aware actions
    - integrate AsyncOrchestratorPlanner (summarizer + memory + remote/local decisions) into runtime planner wiring
    - extend orchestrator decision schema with target_zone and map directional intent into glance/orient_to_zone
    - keep action transaction semantics and style-scaled executor behavior aligned with config-driven style profiles
    - add orchestrator unit coverage for decision parsing and focused local mapping
    [robot.yaml]
2026-02-18 Integrate rolling multi-frame video context into core orchestrator path - add orchestrator-side frame history window and latest-only frame sampling - send multimodal Cosmos requests (text + image_url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
    [robot.yaml]
2026-02-18 Harden orchestrator frame-window + fallback behavior
2026-02-18 Refactor orchestrator to remote-first planning with persistent memory, reasoning traces, robust response parsing, and tuned Cosmos cadence
    [robot.yaml]
2026-02-19 simplified orchestrator architecture to remove local detector inputs currently
    [robot.yaml]
2026-02-19 Ship telemetry V2 sidecar: signal packs, field filters, memory/timeline streams, capture/replay bundles, and viewer/agent robustness improvements
    [robot.yaml]
2026-02-19 Harden runtime safety and parsing: fail-fast loop supervision, safe bool coercion, stale-remote hold fallback, replay path guard, and re-triggerable action IDs
    [main.py]
2026-02-20 reworked memory system. Split back to summarizer + planner architecture. Improved telemetry pipeline.
    [robot.yaml]
2026-02-22 Remote-first behavior hardening, run-scoped logs, and runs-only log sync
    - Strengthened Cosmos env/planner prompting and parsing for temporal sequence handling and cleaner structured extraction.
    - Added planner sanitization (fence stripping + relaxed JSON recovery) and orient-to-zone command repair when zone is missing.
    - Improved behavior robustness around low-quality remote outputs while keeping remote-first decision flow.
    - Added run-scoped logging (logs/runs/<run_id>/...) and timestamped action records (ts_wall_s, ts_monotonic_s).
    - Added DeepStream startup preflight checks; logs clear health warning and degrades detector path safely when dependencies are missing.
    - Updated m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
    [robot.yaml]
2026-02-22 Add behavior v3 - in progress snapshot
    [robot.yaml]
2026-02-23 Upgrade parsing and add abstract model provider approach, to enable google gemini integration for quick testing before pivoting back to Cosmos.
    [robot.yaml]
2026-02-24 Major refactor to hybrid VLM / local state logic behavior layer. Improve test coverage. Create primitive simulator.
    [robot.yaml]
2026-02-26 Overhaul primitive behavior simulator and behavior stack along with broad test updates
    [robot.yaml]
2026-02-28 Primitive sim cleanup, env/planner probe app, telemetry improvements, parsing improvements
    [robot.yaml]
2026-03-01 Initial behavior v4 refactor
    [robot.yaml]
2026-08-05 Checkpoint expressive movement demo before behavior rewrite
    [camera mount fit check 2.step]
2026-08-06 Reset perception and behavior foundations
    [robot.yaml]
2026-09-05 Clean up obsolete tooling and prepare gesture workshop
    Preserve primitive simulation and optional telemetry while retiring V4-dependent tools. Harden configuration and servo command validation, isolate simulator timing, and keep gesture dry-runs hardware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
    Refresh current-state documentation and record the assessment and workshop plan. Validation: 244 tests passed, bounded dummy runtime, dry-run gesture tools, and simulator browser checks. No hardware 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
2026-09-07 Add deterministic manual gesture runtime
    [robot.yaml]
2026-09-08 Add supervised Gemini desk interaction and accepted gestures
    Integrate attention probes, camera preview, and one-shot social responses using the validated desk performance library. Support early thumbs-up as greeting followed by excitement; preserve stale-result and cancellation gates.
    Correct simulator pitch2 direction and add a scripted desk scene. Document physical trial results and remaining live acceptance checks. Validation: 328 tests passed; Mac dummy runtime and Jetson launch checks passed. Early thumbs-up continuation still awaits physical validation.
    [robot.yaml]
2026-09-19 Finalize PALA V1 demo, recording tools, and portfolio documentation
    [robot.yaml]
